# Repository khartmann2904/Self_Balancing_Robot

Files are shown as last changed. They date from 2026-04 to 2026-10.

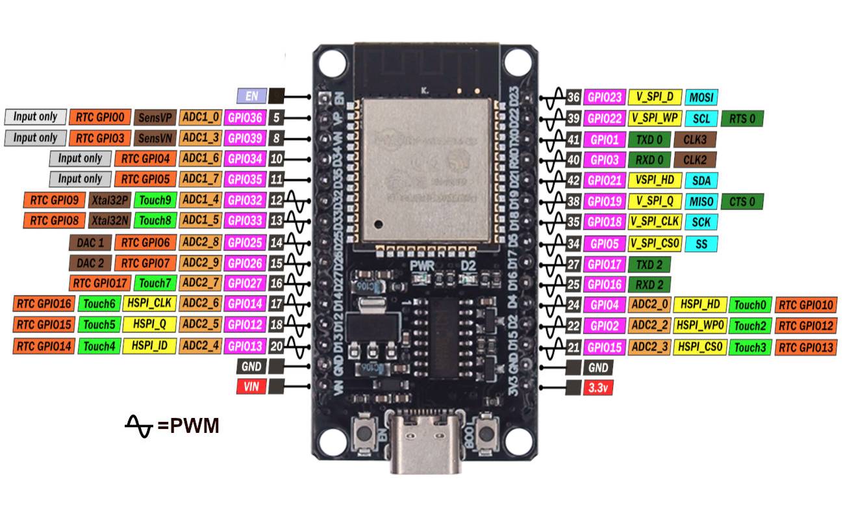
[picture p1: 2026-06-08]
docs/Datasheets/ESP32-DEV-CH340-USBC-003-2047351827.jpg

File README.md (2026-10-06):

# Self-Balancing Robot

> 🚧 **Status: ongoing project.** This robot is actively being developed and tuned — expect frequent changes to the firmware, control loop, and hardware as things get refined.

A two-wheeled, self-balancing robot (inverted pendulum) built around an **ESP32**, driven by an IMU-based cascade PID control loop, with stepper-motor actuation and PS4 controller input for manual driving.

robot

## Hardware

- **Microcontroller:** ESP32 (ESP32-DEV board, CH340 USB-C)
- **IMU:** GY-86 / MPU6050 (accelerometer + gyroscope)
- **Actuation:** NEMA17 stepper motors with TMC2209 stepper drivers
- **Input:** PS4 controller via Bluepad32 (Bluetooth)
- **Chassis:** 3D-printed frame (see `hardware/3D_Printing/`)

## Electrical Circuit



## Control Architecture

The robot uses a **cascade PID control** scheme:

- **Inner loop (balance):** stabilizes the tilt angle using gyro rate as the derivative term (rather than differentiating the angle itself), reacting quickly to keep the robot upright.
- **Outer loop (position hold):** holds the robot's position by feeding a target lean angle into the inner balance loop, correcting for drift.
- **Drive layer:** converts driving commands into a target velocity (mm/s), which is layered on top of the balance/position control so the robot can be driven around with the PS4 controller while still balancing itself.

## Repository Structure

```
Self_Balancing_Robot/
├── docs/
│   └── Datasheets/            # Component datasheets (ESP32 dev board, stepper motor, TMC2209 driver)
├── hardware/
│   ├── 3D_Printing/           # STL/CAD files for the frame and mounts
│   └── Schematics/            # KiCad circuit schematics and PCB files
├── include/                   # Header files
│   ├── BatteryManager.h
│   ├── BluetoothManager.h
│   ├── Config.h               # Central project configuration
│   ├── ControlLoop.h
│   ├── IMUManager.h
│   ├── MotorManager.h
│   └── README
├── lib/                       # PlatformIO project-specific libraries
│   └── README
├── src/                       # Firmware source code
│   ├── BatteryManager.cpp
│   ├── BluetoothManager.cpp
│   ├── ControlLoop.cpp
│   ├── IMUManager.cpp
│   ├── MotorManager.cpp
│   └── main.cpp               # Entry point: setup(), loop(), ties everything together
├── .gitignore
├── platformio.ini             # PlatformIO project configuration
└── README.md
```

## Software Architecture

The firmware is structured around small, single-responsibility classes rather than one monolithic sketch:

- **`Config.h`** — central place for project-wide configuration, so settings live in one file instead of being scattered across the code.
- **`ControlLoop`** — runs the cascaded PID control: the outer loop converts a target speed into a target lean angle, and the inner loop converts that angle error into motor output. Also exposes serial-based live gain tuning.
- **`IMUManager`** — wraps IMU initialization and orientation/angle readout, keeping sensor-specific code out of the control logic.
- **`MotorManager`** — wraps stepper motor control (step generation, direction, enable/disable), keeping hardware I/O out of the control logic.
- **`BluetoothManager`** — handles PS4 controller pairing and input via Bluepad32.
- **`BatteryManager`** — handles battery monitoring.
- **`main.cpp`** — wires the above together: reads sensors, runs the control loop, drives the motors, and handles Bluetooth input.

This separation means the control math can be tested/tuned independently of the IMU or motor driver implementation, and either can be swapped out without touching `ControlLoop`.

## Getting Started

1. Flash `src/main.cpp` to the ESP32 (Arduino IDE or PlatformIO).
2. Wire up the IMU, motor drivers, and motors per [`hardware/Schematics/`](./hardware/Schematics).
3. Adjust the settings in [`include/Config.h`](./include/Config.h) if your setup differs.
4. Power on and hold the robot upright to let it settle into balance.
5. Connect via the serial monitor to tune `Kp`/`Ki`/`Kd` live if needed.
6. Pair a PS4 controller via Bluepad32 for manual drive control.

## TODO
- MotorManager still needs a proper FastAccel library integration

## Notes

This project doubles as a hands-on platform for exploring control theory concepts (PID tuning, cascade control, sensor fusion) alongside embedded systems work (ESP32 firmware, stepper motor control, Bluetooth HID input).

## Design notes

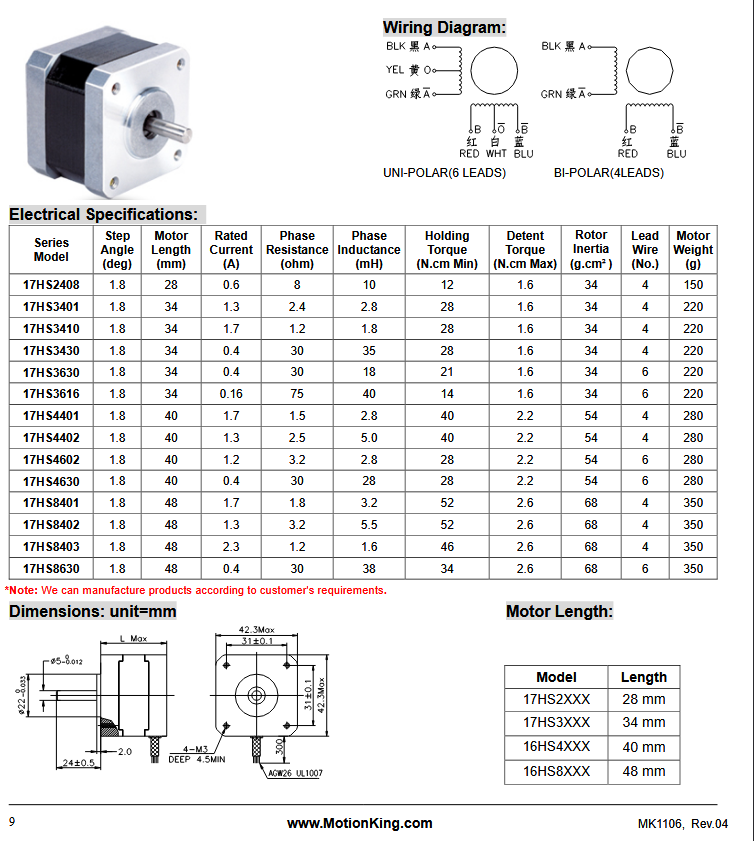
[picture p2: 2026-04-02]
docs/Datasheets/Stepper Motor.png

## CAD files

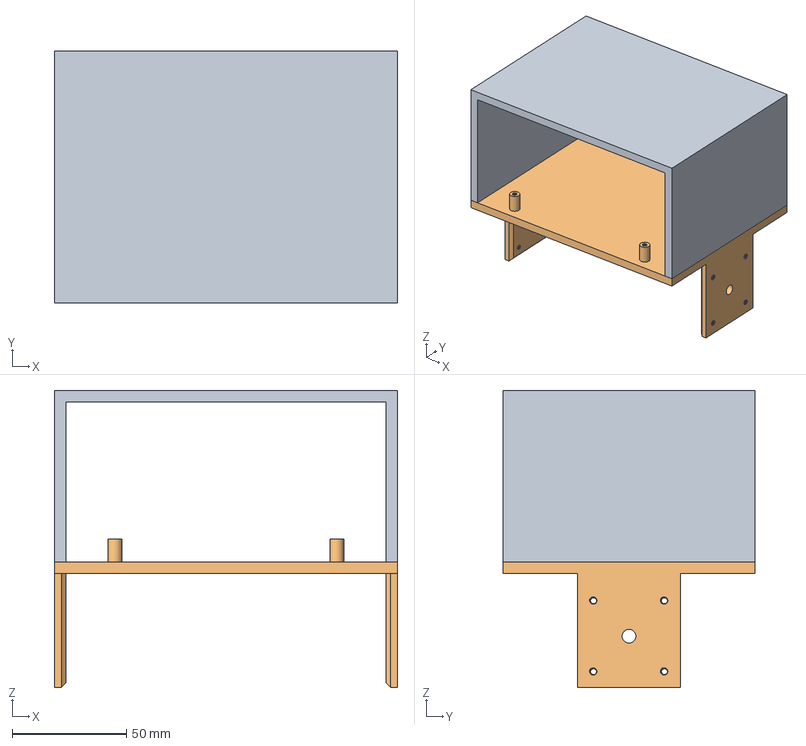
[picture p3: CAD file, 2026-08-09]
hardware/3D_Printing/Chassis.step
150.0 x 110.0 x 130.0 mm

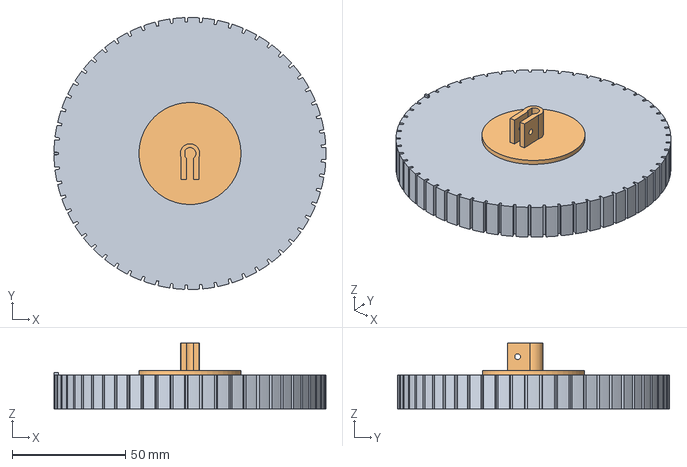
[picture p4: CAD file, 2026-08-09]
hardware/3D_Printing/Wheel.step
120.0 x 120.0 x 29.0 mm

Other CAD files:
hardware/3D_Printing/Chassis.3mf
hardware/3D_Printing/Wheel.3mf

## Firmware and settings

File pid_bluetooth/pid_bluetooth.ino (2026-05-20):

#include <AccelStepper.h>
#include <MPU6050_tockn.h>
#include <Wire.h>
#include <Bluepad32.h>

ControllerPtr myControllers[BP32_MAX_GAMEPADS]; //for the ps4 controller
// Pin Definitions (Matches your KiCad Schematic)
#define LEFT_STEP_PIN  16
#define LEFT_DIR_PIN   17
#define LEFT_EN_PIN 25
#define LEFT_MS1_PIN 33
#define LEFT_MS2_PIN 32
#define RIGHT_STEP_PIN 27
#define RIGHT_DIR_PIN  26
#define RIGHT_EN_PIN 2
#define RIGHT_MS1_PIN 12
#define RIGHT_MS2_PIN 14
// Define the stepper interface type (1 = Driver with Step/Dir pins)
#define MOTOR_INTERFACE_TYPE 1
#define BATTERY_VOLTAGE_PIN 15  //reads battery voltage in order to prevent undercharging

const float R1 = 32000.0;
const float R2 = 10000.0;
const float RATIO = (R1 + R2) / R2;  // = 4.3
const float ADC_REF = 3.3;
const float ADC_RES = 4095.0;

// Initialize the steppers
AccelStepper leftMotor(MOTOR_INTERFACE_TYPE, LEFT_STEP_PIN, LEFT_DIR_PIN);
AccelStepper rightMotor(MOTOR_INTERFACE_TYPE, RIGHT_STEP_PIN, RIGHT_DIR_PIN);
MPU6050 mpu6050(Wire);

//PID Constants
float kp = 30.0;   // Start small (try 10-50)
float ki = 0.1;    // Start very small (try 0.1-1.0)
float kd = 2.5;    // Start small (try 1.0-5.0)

float targetAngle = 0.0; // The "Perfectly Level" goal
float error, lastError, integratedError, derivative;
float motorSpeed;

unsigned long lastTime;

//##########BatteryVoltage################
float readBatteryVoltage() {
    long sum = 0;
    for (int i = 0; i < 64; i++) {
        sum += analogRead(BATTERY_VOLTAGE_PIN);
        delay(5);
    }
    float vout = ((sum / 64.0) / ADC_RES) * ADC_REF;
    float voltage = vout * RATIO;
    return voltage * (10.5 / 12.8); // correction factor = 0.777
}
//#############PS4_CONTROLLER######################
void onConnectedController(ControllerPtr ctl) {
    if (myControllers[0] == nullptr) {
        Serial.println("Controller connected!");
        myControllers[0] = ctl;
        ctl->setColorLED(0, 255, 0); // Green LED on PS4 controller
    }
}

void onDisconnectedController(ControllerPtr ctl) {
    for (int i = 0; i < BP32_MAX_GAMEPADS; i++) {
        if (myControllers[i] == ctl) {
            Serial.println("Controller disconnected");
            myControllers[i] = nullptr;
        }
    }
}

float processGamepad(ControllerPtr ctl) {
    // Get r2 and l2 button values (0-1023)
    int r2 = ctl->throttle();   // Left stick Y-axis (forward/backward)
    int l2 = ctl->brake();   // Left stick X-axis (left/right)
    int angleCorrection = 0;
    // Simple tank drive control
    if (r2 > 0) {
        // Forward
        int angleCorrection = map(abs(r2), 0, 1023, 0, 5);  //this translates the joystick to a 5 degree angle
        Serial.println(angleCorrection);
        return angleCorrection;
    } 
    else if (l2 > 0) {
        // Reverse
        int angleCorrection = map(abs(l2), 0, 1023, 0, -5);  //this translates the joystick to a 5 degree angle
        Serial.println(angleCorrection);
        return angleCorrection;
    }
    else{
      targetAngle= 0.0;
      angleCorrection = 0; 
    }
    // Button example - emergency stop
    if (ctl->a()) { 
        // Stop all motors, if x button on ps4-controller gets pressed
        digitalWrite(LEFT_EN_PIN, HIGH);  //EN_PINS get activated to shut off motors
        digitalWrite(RIGHT_EN_PIN, HIGH);
    }
    return angleCorrection;
}



void setup() {
 // Set a constant speed (Steps per second)
  // 800 steps/sec = 1/4 turn per second at 1/16 microstepping
  Serial.begin(115200);
  //PS4_CONTROLLER SETUP
  BP32.setup(&onConnectedController, &onDisconnectedController);
  BP32.forgetBluetoothKeys();  // Optional: clear previous pairings

  Wire.begin(); // Starts I2C communication
  
  mpu6050.begin();
  // This calculates the 'offset' so your robot knows what 'zero' is.
  // Make sure the GY-87 is perfectly level during this!
  mpu6050.calcGyroOffsets(true); 
  
  Serial.println("Done!");


  leftMotor.setMaxSpeed(10000);  // Higher ceiling

  rightMotor.setMaxSpeed(10000);

  pinMode(LEFT_EN_PIN, OUTPUT); 
  pinMode(RIGHT_EN_PIN, OUTPUT);
  pinMode(LEFT_MS1_PIN, OUTPUT);  //The combination of HIGH and LOW MS_PINS decides on the step size of the motors
  pinMode(RIGHT_MS1_PIN, OUTPUT);
  pinMode(LEFT_MS2_PIN, OUTPUT);
  pinMode(RIGHT_MS2_PIN, OUTPUT);
  pinMode(BATTERY_VOLTAGE_PIN, INPUT);

  digitalWrite(LEFT_EN_PIN, LOW); //Turns on the motors
  digitalWrite(RIGHT_EN_PIN, LOW);

  digitalWrite(LEFT_MS1_PIN, LOW);  //The combination of HIGH and LOW MS_PINS decides on the step size of the motors
  digitalWrite(RIGHT_MS1_PIN, LOW);
  digitalWrite(LEFT_MS2_PIN, LOW);
  digitalWrite(RIGHT_MS2_PIN, LOW);

}
void loop() {
  mpu6050.update(); //updates gyroscope
  unsigned long currentTime = millis(); //tracks time

  BP32.update();  //updates ps4-controller
  for (int i = 0; i < BP32_MAX_GAMEPADS; i++) {
      ControllerPtr ctl = myControllers[i];
      if (ctl && ctl->isConnected() && ctl->hasData()) {
          targetAngle = processGamepad(ctl);
      }
  }
  
  // PID runs every 5ms
  if (currentTime - lastTime >= 5) {
    float currentAngle = mpu6050.getAngleX();
    
    // 1. Calculate Error
    error = currentAngle - targetAngle;
    
    // 2. Proportional Term
    float P = kp * error;
    
    // 3. Integral Term
    integratedError += error;
    integratedError = constraint(integratedError, -500, 500); 
    float I = ki * integratedError;
    
    // 4. Derivative Term
    derivative = error - lastError;
    float D = kd * derivative;
    
    // 5. Total Output
    motorSpeed = P + I + D;
    
    // Safety: Kill motors if tipped too far
    if (abs(currentAngle) > 40) {
      digitalWrite(LEFT_EN_PIN, HIGH);
      digitalWrite(RIGHT_EN_PIN, HIGH);
      motorSpeed = 0;
    } else {
      digitalWrite(LEFT_EN_PIN, LOW);
      digitalWrite(RIGHT_EN_PIN, LOW);
    }

    // Apply to motors
    leftMotor.setSpeed(-motorSpeed);
    rightMotor.setSpeed(motorSpeed);
    
    lastError = error;
    lastTime = currentTime;
    
    // Debug output (optional - can slow things down)
    //Serial.print("Angle: "); Serial.print(currentAngle);
    //Serial.print(" | Speed: "); Serial.println(motorSpeed);
  }

  // CRITICAL: These must run every loop iteration
  leftMotor.runSpeed();
  rightMotor.runSpeed();
  
  // Battery check - only once per second, NON-BLOCKING
  static unsigned long lastBatteryCheck = 0;
  if (currentTime - lastBatteryCheck >= 1000) {
    static int sampleCount = 0;
    static long voltageSum = 0;
    
    // Take one sample per loop, accumulate over time
    if (sampleCount < 64) {
      voltageSum += analogRead(BATTERY_VOLTAGE_PIN);
      sampleCount++;
    } else {
      // Calculate voltage from accumulated samples
      float vout = ((voltageSum / 64.0) / ADC_RES) * ADC_REF;
      float voltage = vout * RATIO * (10.5 / 12.8);
      
      Serial.print("Battery: "); Serial.println(voltage);
      
      if(voltage <= 9.0) {
        digitalWrite(LEFT_EN_PIN, HIGH);
        digitalWrite(RIGHT_EN_PIN, HIGH);
      }
      
      // Reset for next reading
      sampleCount = 0;
      voltageSum = 0;
      lastBatteryCheck = currentTime;
    }
  }
}


// Simple helper to keep numbers in range
float constraint(float val, float minVal, float maxVal) {
  if (val < minVal) return minVal;
  if (val > maxVal) return maxVal;
  return val;



}

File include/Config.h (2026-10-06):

#pragma once    // include file only once in a single compilation
#include <Arduino.h>

// ---------------------------------------------------------------- Pins (ESP32)
#define LEFT_STEP_PIN        16
#define LEFT_DIR_PIN         17
#define LEFT_EN_PIN          25
#define LEFT_MS1_PIN         33
#define LEFT_MS2_PIN         32
#define RIGHT_STEP_PIN       27
#define RIGHT_DIR_PIN        26
#define RIGHT_EN_PIN          2
#define RIGHT_MS1_PIN        12   
#define RIGHT_MS2_PIN        14
#define BATTERY_VOLTAGE_PIN  15   // analog input, voltage divider to measure battery voltage

// ---------------------------------------------------------------- Battery
constexpr float         BATTERY_R1_OHMS          = 32000.0f;   // divider: top resistor
constexpr float         BATTERY_R2_OHMS          = 10000.0f;   // divider: bottom resistor,
constexpr float         BATTERY_LOW_THRESHOLD_V  = 9.6f;       // lowest voltage for the motors to work properly (3.2 V per cell, 3S LiPo)
constexpr uint8_t       BATTERY_LOW_SAMPLES      = 5;          // consecutive low readings before latching
constexpr unsigned long BATTERY_CHECK_PERIOD_US  = 100000UL;   // 10 Hz, UL -> unsigned long

// ---------------------------------------------------------------- IMU
constexpr float IMU_PITCH_OFFSET_DEG = 0.0f;    // mounting offset so 0 deg = balance point
constexpr float IMU_GYRO_WEIGHT      = 0.98f;   // complementary filter: gyro share

// ---------------------------------------------------------------- Mechanics
// The MS pins are set LOW/LOW in setup(), which is 8x microstepping on a TMC2209.
constexpr float STEPS_PER_REV    = 200.0f;
constexpr float MICROSTEPS       = 8.0f;
constexpr float WHEEL_DIAMETER_MM = 70.0f;
constexpr float MM_PER_STEP      = (PI * WHEEL_DIAMETER_MM) / (STEPS_PER_REV * MICROSTEPS);

// ---------------------------------------------------------------- Motors
// Upper limit for the step rate in steps/s. runSpeed() emits at most one step per
// call, so the real limit is also how often loop() runs.
constexpr float MAX_STEP_RATE = 4000.0f;

// ---------------------------------------------------------------- Control
constexpr unsigned long CONTROL_PERIOD_US = 5000;   // 200 Hz
constexpr float FALL_ANGLE_DEG            = 40.0f;  // motors off beyond this
constexpr float ARM_ANGLE_DEG             = 3.0f;   // must be within this angle to arm the robot (and reset stale positions)

constexpr float POSITION_BIAS_LIMIT_DEG   = 10.0f;   // max lean the position loop may request
constexpr float POSITION_INTEGRAL_LIMIT   = 50.0f;  // mm*s
constexpr float ANGLE_I_MAX_OUT           = 100.0f; // max contribution of the angle I-term (steps/s)

// Flip to -1.0f if the robot runs away instead of returning when pushed.
constexpr float POSITION_SIGN             = 1.0f;

// ---------------------------------------------------------------- Bluetooth / joystick
constexpr int   STICK_DEADZONE         = 60;      // Bluepad32 axes: about -511..512
constexpr int   STICK_MAX              = 512;
constexpr float MAX_LEAN_DEG           = 8.0f;    // lean angle at full stick
constexpr float DRIVE_SLEW_DEG_PER_S   = 30.0f;   // how fast the lean command may change
constexpr bool  BT_FORGET_KEYS_ON_BOOT = false;   // true = re-pair the controller every boot

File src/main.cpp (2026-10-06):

#include <Arduino.h>
#include "Config.h"
#include "IMUManager.h"
#include "MotorManager.h"
#include "ControlLoop.h"
#include "BatteryManager.h"
#include "BluetoothManager.h"

// Instantiate objects
IMUManager       imu(IMU_PITCH_OFFSET_DEG);
MotorManager     motors(LEFT_STEP_PIN, LEFT_DIR_PIN, LEFT_EN_PIN,
                        RIGHT_STEP_PIN, RIGHT_DIR_PIN, RIGHT_EN_PIN);
BatteryManager   battery(BATTERY_VOLTAGE_PIN, BATTERY_R1_OHMS, BATTERY_R2_OHMS, BATTERY_LOW_THRESHOLD_V);
BluetoothManager bluetooth;

// Controller parameters (Kp, Ki, Kd)
PIDGains anglePID    = {0.0f, 0.0f, 0.0f};    // inner loop: balance angle
PIDGains positionPID = {0.0f, 0.0f, 0.0f};    // outer loop: position hold
ControlLoop controller(anglePID, positionPID);

unsigned long lastControlTime  = 0;
unsigned long lastBatteryCheck = 0;
bool batteryLow = false;
bool armed      = false;   // motors only run after the robot was held upright
bool serialStop = false;   // set by the serial command "stop", cleared by "start"

void setup() {
    Serial.begin(115200);

    // MS pins: LOW/LOW = 8x microstepping on the TMC2209 (must match MICROSTEPS in Config.h)
    pinMode(LEFT_MS1_PIN, OUTPUT);
    pinMode(LEFT_MS2_PIN, OUTPUT);
    pinMode(RIGHT_MS1_PIN, OUTPUT);
    pinMode(RIGHT_MS2_PIN, OUTPUT);
    digitalWrite(LEFT_MS1_PIN, LOW);
    digitalWrite(RIGHT_MS1_PIN, LOW);
    digitalWrite(LEFT_MS2_PIN, LOW);
    digitalWrite(RIGHT_MS2_PIN, LOW);

    motors.begin();     // first, so the drivers are disabled during IMU calibration
    while (!imu.begin()) {
        Serial.println("IMU nicht gefunden - bitte Verkabelung pruefen.");
        delay(1000);
    }
    bluetooth.begin();

    lastControlTime  = micros();
    lastBatteryCheck = micros();
    Serial.println("System erfolgreich gestartet.");
}

void loop() {
    motors.run();   // emit step pulses as often as possible

    const unsigned long now = micros(); // current time since boot in microseconds

    // Bluepad32 must be updated continuously to process controller input.
    bluetooth.update();
    controller.handleSerialTuning();    // non-blocking: reads serial input and updates PID gains if a tuning command was received

    // Serial "stop" takes effect immediately, not only at the next control tick.
    if (controller.takeStopRequest()) {
        serialStop = true;
        motors.enableMotors(false);
        controller.reset();
        armed = false;  // turns off the motors and clears stale positions
    }
    if (controller.takeStartRequest()) {
        serialStop = false; // allows the control loop to run again
    }

    // Battery check at set frequenzy; the result is latched inside BatteryManager.
    if ((now - lastBatteryCheck) >= BATTERY_CHECK_PERIOD_US) {
        lastBatteryCheck = now;
        batteryLow = battery.isBatteryLow();
        if (batteryLow) {
            Serial.println("Warnung: Batteriespannung niedrig! Motoren werden deaktiviert.");
        }
    }
    if (batteryLow) {   
        motors.enableMotors(false);
        controller.reset();
        armed = false;
        return;
    }

    // Control loop at fixed frequency (200 Hz). The time since the last tick is passed to the controller for integral and derivative calculations.
    if ((now - lastControlTime) >= CONTROL_PERIOD_US) {
        const float dt = (now - lastControlTime) / 1000000.0f; // passed time since last control tick in seconds
        lastControlTime = now;

        imu.update();
        const float currentAngle = imu.getPitch();
        const float gyroRate     = imu.getGyroX();

        // Safety cutoff: serial stop, emergency stop button or a fall
        if (serialStop || bluetooth.isEmergencyStopPressed() || fabsf(currentAngle) > FALL_ANGLE_DEG) {
            motors.enableMotors(false);
            controller.reset();
            armed = false;
            return;
        }

        // (Re-)arm only when the robot is held close to upright. Clears stale positions.
        if (!armed) {
            if (fabsf(currentAngle) > ARM_ANGLE_DEG) return;
            motors.resetPositions();
            controller.reset(); // clears stale integrals and position error of the cascade controller
            motors.enableMotors(true);
            armed = true;
        }

        const bool joystickActive = bluetooth.isJoystickActive();
        if (joystickActive) {   // reset the position hold when the joystick is moved, otherwise the robot may run away when the stick is released
            motors.resetPositions();    // clears stale positions
        }

        const float motorCommand = controller.computeCascade(
            bluetooth.getDriveCommand(),      // desired lean angle in degrees
            motors.getLeftPosition(),
            motors.getRightPosition(),
            currentAngle,
            gyroRate,
            joystickActive,
            dt);

        // The sign depends on how the motors are wired
        motors.setSpeeds(-motorCommand, -motorCommand);
    }

    
}

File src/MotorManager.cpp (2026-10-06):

#include "MotorManager.h"
#include "Config.h"

MotorManager::MotorManager(uint8_t stepPinL, uint8_t dirPinL, uint8_t enPinL,
                           uint8_t stepPinR, uint8_t dirPinR, uint8_t enPinR)
    : stepL(stepPinL), dirL(dirPinL), enL(enPinL),
      stepR(stepPinR), dirR(dirPinR), enR(enPinR),
      leftMotor(AccelStepper::DRIVER, stepPinL, dirPinL),
      rightMotor(AccelStepper::DRIVER, stepPinR, dirPinR),
      enabled(false) {}

void MotorManager::begin() {
    pinMode(stepL, OUTPUT);
    pinMode(dirL, OUTPUT);
    pinMode(enL, OUTPUT);
    pinMode(stepR, OUTPUT);
    pinMode(dirR, OUTPUT);
    pinMode(enR, OUTPUT);

    digitalWrite(enL, HIGH);   // start disabled (EN is active low); main() arms the robot
    digitalWrite(enR, HIGH);
    enabled = false;

    leftMotor.setMaxSpeed(MAX_STEP_RATE);
    rightMotor.setMaxSpeed(MAX_STEP_RATE);
    leftMotor.setCurrentPosition(0);
    rightMotor.setCurrentPosition(0);
}

void MotorManager::enableMotors(bool en) {
    if (en == enabled) return;
    enabled = en;
    if (!en) {
        // Stop the step generator too, otherwise it keeps counting steps while disabled.
        leftMotor.setSpeed(0.0f);
        rightMotor.setSpeed(0.0f);
    }
    digitalWrite(enL, en ? LOW : HIGH);
    digitalWrite(enR, en ? LOW : HIGH);
}

void MotorManager::resetPositions() {
    leftMotor.setCurrentPosition(0);
    rightMotor.setCurrentPosition(0);
}

void MotorManager::setSpeeds(float leftSpeed, float rightSpeed) {
    if (!enabled) {
        leftSpeed = 0.0f;
        rightSpeed = 0.0f;
    }
    leftMotor.setSpeed(constrain(leftSpeed, -MAX_STEP_RATE, MAX_STEP_RATE));
    rightMotor.setSpeed(constrain(rightSpeed, -MAX_STEP_RATE, MAX_STEP_RATE));
}

void MotorManager::run() {
    leftMotor.runSpeed();
    rightMotor.runSpeed();
}

long MotorManager::getLeftPosition() {  // Accelstepper tracks the position in steps, not mm
    return leftMotor.currentPosition(); // Counts up when the motor is driven forward, down when driven backward. The sign depends on how the motor is wired.
}

long MotorManager::getRightPosition() {
    return rightMotor.currentPosition();
}

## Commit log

2026-04-02 Initial Upload
    [Schaltplan.kicad_pcb, Schaltplan.kicad_sch, Self-Balancing Robot v1.3mf]
2026-04-02 PID Controller added
2026-05-20 added ps4 controller as input device
2026-06-08 Major changes in pid controller and bluetooth connection for ps4 controller
    [Self-Balancing Robot v1.3mf]
2026-08-06 3d printing files
    [Chassis.3mf, Chassis.step, Wheel.3mf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]
2026-08-08 New file names
    [Schaltplan.kicad_sch]
2026-08-08 Added circuit changes
    [Schaltplan.kicad_sch]
2026-08-09 PlatfromIO added
    [Chassis.3mf, Chassis.step, Schaltplan.kicad_pcb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]
2026-08-30 Pin numbers added and comments added
2026-08-30 BatteryManager and Bluetooth added, BatteryManager already implemented
2026-08-30 changed folder name
    [Schaltplan.kicad_pcb, Schaltplan.kicad_sch]
2026-08-31 Refactor project structure and update dependencies
    - Updated launch configuration paths in .vscode/launch.json for new user directory.
    - Changed project status section in README.md to reflect current to-do items.
    - Added FastAccelStepper and Bluepad32 libraries to platformio.ini.
    - Removed old BatteryManager, BluetoothManager, ControlLoop, IMUManager, and MotorManager header files.
    - Implemented new BatteryManager, BluetoothManager, ControlLoop, IMUManager, and MotorManager header files in the include directory.
    - Added BluetoothManager implementation in BluetoothManager.cpp.
    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
2026-09-02 comments changed from german to english and motormanger functions were implemented
2026-09-02 Add MPU6050 support to IMUManager and update platformio.ini dependencies
2026-09-02 Refactor control loop timing and battery monitoring; remove test README
2026-09-02 Update README and main.cpp for BluetoothManager implementation and battery monitoring
2026-09-03 WIP: updated ControlLoop, IMUManager, MotorManager integration - untested
2026-09-03 Refactor ControlLoop and IMUManager; remove unused computeCascade method and add comments for clarity
2026-09-03 Refactor MotorManager constructor to include enable pins; add handleSerialTuning method to ControlLoop for PID tuning via serial
2026-09-16 Refactor IMUManager to accept pitch offset, update launch configurations, and enhance BluetoothManager and ControlLoop logic
    - Modified IMUManager constructor to accept a pitch offset for calibration.
    - Updated pitch calculation in IMUManager to include the pitch offset.
    - Adjusted launch.json paths for user-specific directories.
    - Added a new unwanted recommendation in extensions.json.
    - Cleaned up BluetoothManager update method for clarity.
    - Enhanced ControlLoop with comments for better understanding of calculations.
    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
2026-09-17 Refactor MotorManager constructor and enhance setup in main.cpp for motor control
2026-09-19 Refactor ControlLoop and MotorManager to improve method signatures and enhance functionality; update BatteryManager for voltage averaging; modify main loop for motor control and serial tuning
2026-09-19 Refactor and enhance code structure for improved readability and functionality
    - Replaced include guards with #pragma once in header files for better compatibility.
    - Introduced a new Config.h file to centralize pin definitions and constants.
    - Updated BatteryManager to include lowCount and latched state for better battery monitoring.
    - Enhanced BluetoothManager to include joystick input handling and slew-limiting for drive commands.
    - Refactored ControlLoop to separate angle and position PID gains, improving control logic.
    - Improved IMUManager to utilize a complementary filter for angle calculations.
    - Refactored MotorManager to handle motor enabling/disabling more efficiently.
    - Updated m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
    [BatteryManager.cpp, Config.h, ControlLoop.cpp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]
2026-09-19 Refactor ControlLoop and main loop to implement serial stop/start commands; update PID gains for improved control response
2026-09-25 Refactor Config.h to improve comments and clarify pin usage for battery and motor configurations
2026-10-06 Improve safety checks in ControlLoop to prevent division by zero and enhance IMU initialization logic
    [ControlLoop.cpp, main.cpp]
2026-10-06 Refactor ControlLoop and MotorManager for clarity and maintainability
2026-10-06 Adjust control parameters and improve comments for clarity in Config, ControlLoop, IMUManager, and main files
